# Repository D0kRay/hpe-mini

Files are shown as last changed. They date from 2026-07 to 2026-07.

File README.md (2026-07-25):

# hpe-mini

Clean Hellen One starter structure for a custom rusEFI-compatible PCB.

## Repository Layout
- `hellen-one/` - Hellen One scripts and modules (git submodule)
- `kicad-libraries/` - shared KiCad libraries (git submodule)
- `boards/` - generated board outputs by revision
- `docs/` - project notes and pinout plans
- `gerber/` - frame export staging from KiCad

## Quick Start
1. Create your KiCad frame project at repository root.
2. Use revision settings from `revision.txt`.
3. Run `./step1_build_docker.sh` once to build local Hellen image.
4. Run `./step2_copy.sh` to export frame data.
5. Run `./step3_create_board.sh` to merge modules and generate fab outputs.

## GitHub Automation
This repository includes reusable workflows in `.github/workflows/` that call
the upstream Hellen One board creation pipelines.

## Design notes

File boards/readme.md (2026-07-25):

Generated board outputs are organized by revision.

Expected first output path:
- boards/hpe_mini-a/

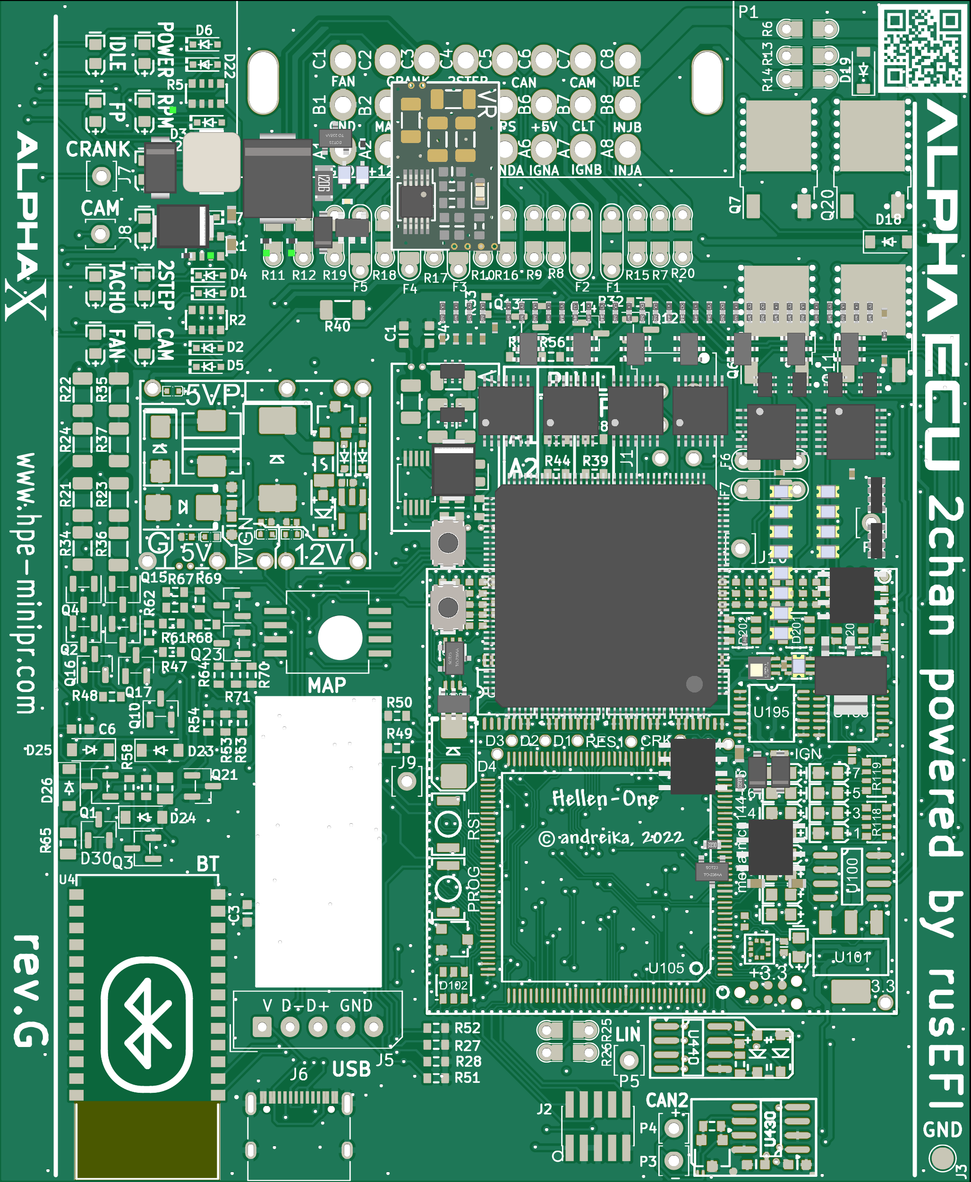
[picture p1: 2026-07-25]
boards/hpe_mini-a/board/hpe_mini-a.png

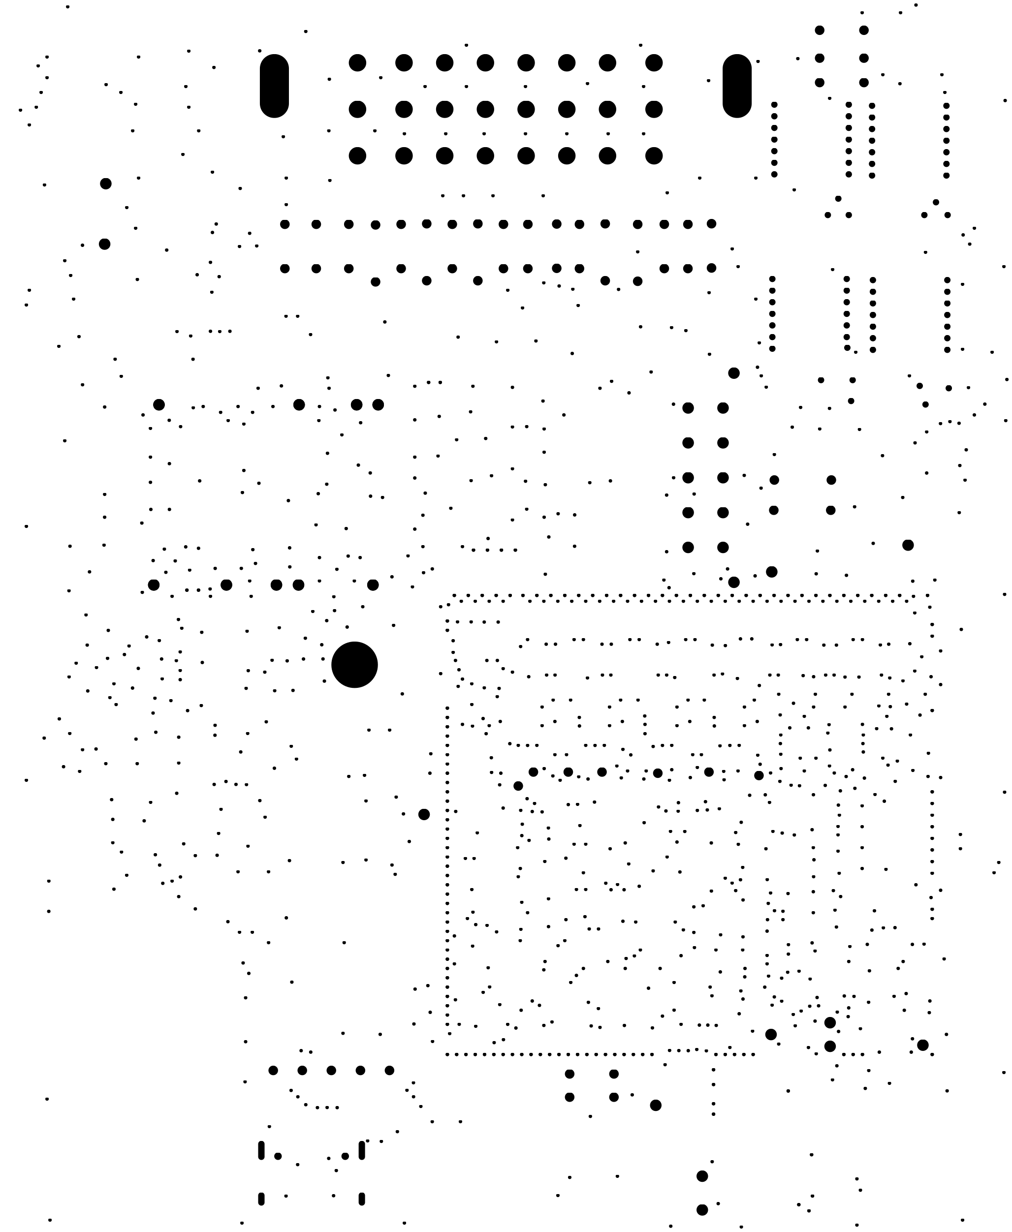
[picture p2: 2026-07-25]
boards/hpe_mini-a/board/misc/hpe_mini-a-outline.png

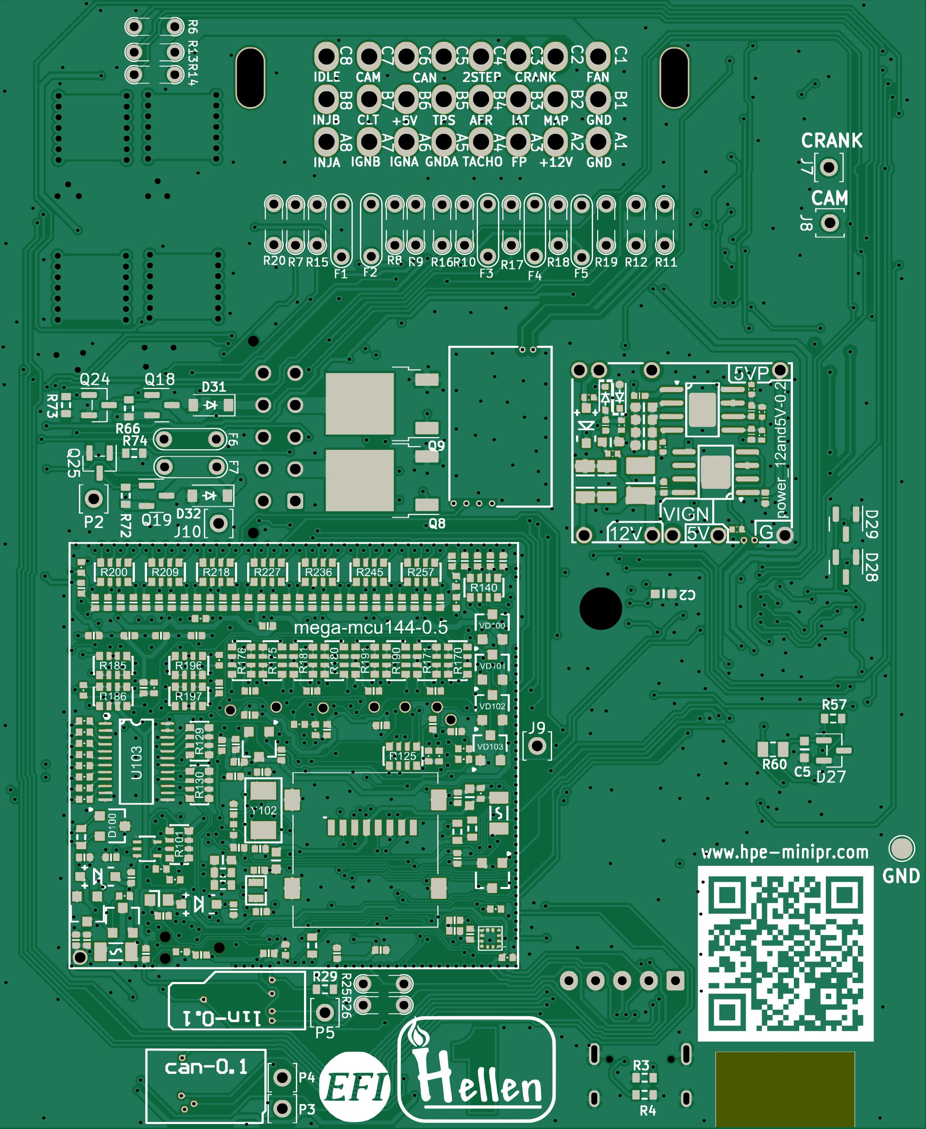
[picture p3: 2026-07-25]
boards/hpe_mini-a/board/misc/hpe_mini-a-bottom.png

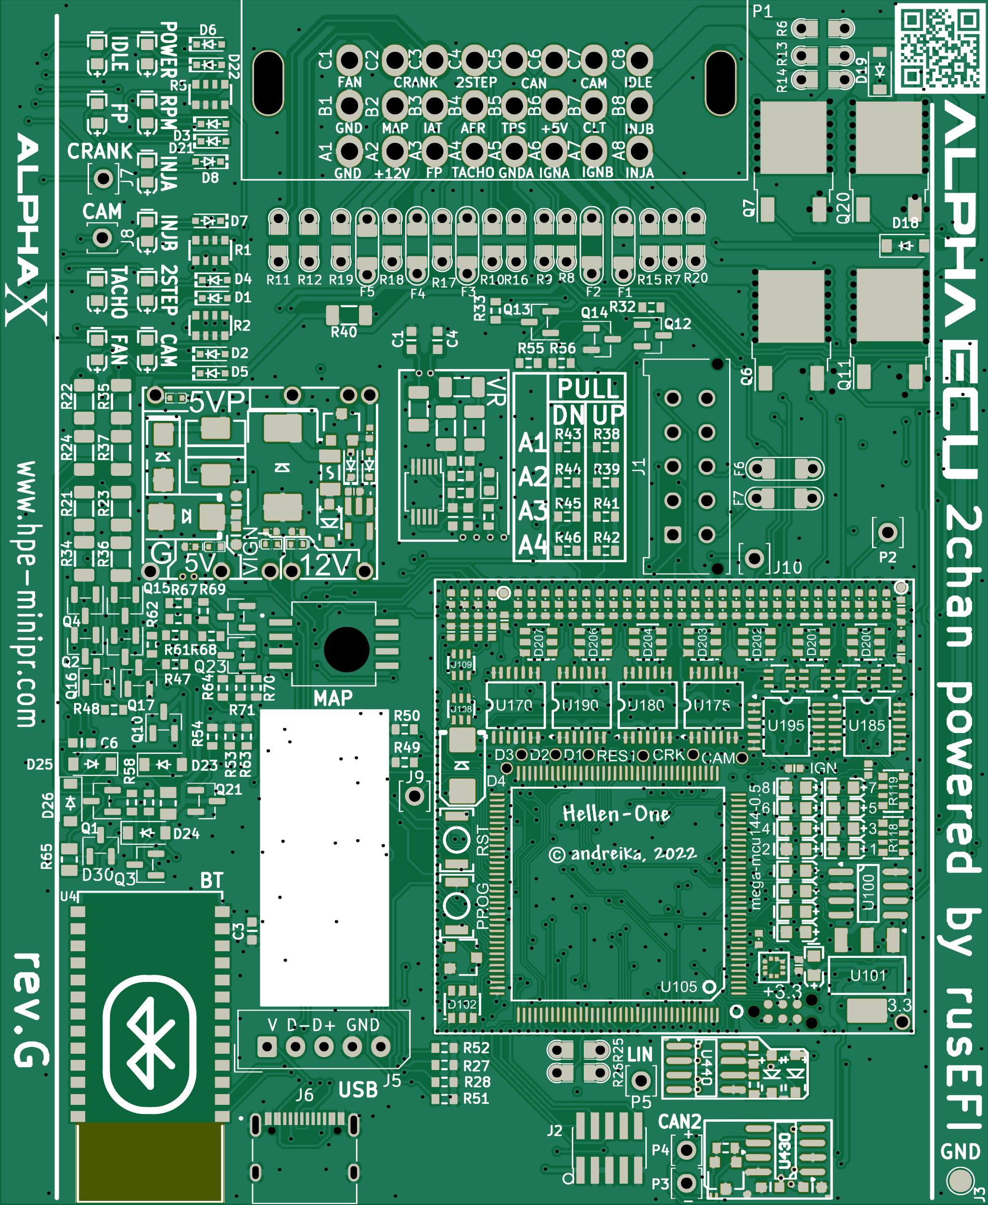
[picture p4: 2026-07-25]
boards/hpe_mini-a/board/misc/hpe_mini-a-top.png

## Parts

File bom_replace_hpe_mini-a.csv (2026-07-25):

# remove the jumper connection from VCC_PP1 to +5V: we need +12v power supply for push-pull outputs.
R309
# remove +5V pull-ups from SPI1 | because we use it with +3.3v accelerometer
R103
R105
# remove jumper resistor connecting BOOT1 with A22 input line | because we use STM32F4
R131
# remove built-in V5A power source from the MCU module | and use an external source (TLS115)
L101
# STM32
U105 | STM32F407ZGT7 | LQFP144 | C1337111
# Alpha2Ch: We don't use SENS1-SENS4 and AUX1-AUX4 | so we don't need these OpAmps
U102
U109
# DC-DC Inductor
L421 | MWSA0503S-100MT | MWSA0503 | C408412
L420 | LBC3225T2R2MR | L1210 | C223413
# LMR14020->LMR14030 (more power | no problem)
U420 | LMR14030 | SOP8 | C182078
#fuses
F410 | nSMD050-24V | SMD1206 | C70076
F300 | nSMD050-24V | SMD1206 | C70076
F1 | Fuse-5A-1206 | SMD1206 | C553924
F2 | Fuse-5A-1206 | SMD1206 | C553924
F3 | Fuse-5A-1206 | SMD1206 | C553924
#power distribution
U103 | AP2331W-7 | SOT-23 | C460346
U480 | AP2331W-7 | SOT-23 | C460346
# JLC-BOM stock shortages...
U420 | LMR14020SDDAR | SOP8 | C187824
S1 | TS-1088R-02026 | SMD-2_2.9x3.9x1.7 | C455280
S2 | TS-1088R-02026 | SMD-2_2.9x3.9x1.7 | C455280
F5 | 0437005.WR | PAD-1206-PAD | C99541
L420 | NLV32T-2R2J-PF | L1210 | C89016
R4 | 4D03WGF1001T5E | R0603-4 | C425239
# no TLS115
U1 | TLS115 | PG-DSO-8-43
# no Cortex 5x2 header
J2 | Cortex_Debug | PinHeader_2x05_P1.27mm_Vertical_SMD
# no MAP sensor
U3 | MPXH6400A | MPXH6400A-SSOP8
# no smart MOSFETs
Q6 | VND14NV04-E | DPAK
Q7 | VND14NV04-E | DPAK
Q8 | VND14NV04-E | DPAK
Q9 | VND14NV04-E | DPAK

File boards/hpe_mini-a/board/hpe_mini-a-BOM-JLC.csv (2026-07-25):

Comment | Designator | Footprint | LCSC Part #
100n | C2, C3, C5, C6, C772, C440, C430, C431 | C0603 | C14663
1N4148WS | D1, D2, D3, D4, D5, D6, D7, D8, D21, D22, D410, D412, D413, D414 | SOD-323 | C2128
LED-RED-0603 | D9, D13, D14, D15, D16, D17, D103 | LED-0603 | C2286
LED-WHITE-0603 | D10, D11, D12 | LED-0603 | C2290
B5819W | D18, D19, D23, D24, D25, D26, D31, D32, D416, D417, D101, D107, D440, D441 | SOD-123 | C8598
LED-GREEN-0603 | D20, D104, D108, D771 | LED-0603 | C72043
PSM712-LF | D27, D30, D411 | SOT-23 | C32677
BAT54S | D28, D29, VD100, VD101, VD102, VD103 | SOT-23 | C47546
nSMD005 | F6, F7 | PAD-1206-PAD | C70064
nSMD050 | F4 | PAD-1206-PAD | C720075
430451012 | J1 | Molex_Micro-Fit_3.0_43045-1012_2x05_P3.00mm_Vertical | C239457
USB_C_Receptacle_USB2.0 | J6 | USB_C_Receptacle_XKB_U262-16XN-4BVC11 | C2927038
HCCPHPE24BKA90F | P1 | 33311-24AW-2 | C5349068
AO3401A | Q1, Q2, Q4, Q5, Q12, Q13, Q15, Q100, Q102 | SOT-23 | C15127
AO3400A | Q3, Q10, Q14, Q16, Q17, Q21, Q22, Q23, Q24, Q25, Q101, Q103 | SOT-23 | C20917
VND14NV04-E | Q11, Q20 | DPAK | C155647
PJM2319PSA | Q18, Q19 | SOT-23 | C411720
4.7k | R1, R2, R5, R125, R170, R171, R175, R176, R180, R181, R185, R186, R190, R191, R196, R197, R200, R209, R218, R227, R236, R245, R257 | R0603-4 | C66697
5.6k | R3 | R0603 | C23189
Jumper-Pad-Pad | R6, R7, R8, R9, R10, R11, R12, R13, R14, R15, R16, R17, R18, R19, R20 | PAD-0805-PAD | C17477
2k | R21, R23, R34, R36 | R1206 | C17944
4.7k | R22, R24, R35, R37, R771, R772, R773, R774 | R1206 | C17936
4.7k | R27, R28, R29, R47, R48, R49, R50, R51, R52, R53, R54, R55, R56, R57, R58, R59, R61, R62, R63, R64, R66, R70, R71, R72, R73, R74 | R0603 | C23162
3.3k | R30, R67 | R0603 | C22978
750 | R31 | R0805 | C17818
2.7k | R32, R33 | R0603 | C13167
SMD1206B035TF/16 | R40, F100, F101 | R1206 | C269114
680k | R43, R44, R45, R46 | R0603 | C25822
220 | R60 | R0805 | C17557
470 | R65 | R0805 | C17710
1.2k | R68, R69 | R0603 | C22765
47u | C410, C412 | C1206 | C96123
100n | C411, C413, C420 | C0402 | C307331
1u | C414, C415 | C0402 | C52923
10u | C421, C422, C423, C424, C425, C426 | C0603 | C96446
4.7u | C427 | C0603 | C19666
10n | C428, C202, C208, C209, C210, C211, C212, C213, C214, C215 | C0402 | C15195
220p | C429 | C0402 | C1530
SMCJ30A | D418 | SMC | C310046
SS34 | D420 | SMA | C8678
P6SMB6.8CA | D421, D205 | SMB | C78395
MHT136UGCT | LED1, LED2, LED3, LED4 | LED0402 | C434447
6.8k | R410, R413 | R0402 | C25917
33k | R411, R424, R425 | R0402 | C25779
1 | R420 | R0402 | C25086
10k | R421, R426, R427, R102, R107, R108, R109, R121, R124, R126, R127, R128, R132, R135, R136, R137, R138, R139, R141, R142, R228, R229, R230, R231, R232, R233, R234, R235, R246, R247, R248, R249, R250, R251, R252, R253 | R0402 | C25744
68k | R422 | R0402 | C36871
12k | R423 | R0402 | C25752
4.7k | R428, R144, R210, R211, R212, R213, R214, R215, R216, R217, R219, R220, R223, R224 | R0402 | C25900
MIC5205-3.3YM5 | U410 | SOT23-5 | C37970
TLS115 | U411 | PG-DSO-8 EP | C540242
TJA1051T/3/1J | U100, U430 | SO8 | C38695
SRV05-4-P-T7 | D102, D200, D201, D202, D203, D204, D206, D207 | SOT23-6 | C85364
SN74LVC1G06DCKR | U110 | SOT-353 | C7828
PESD1CAN | D100, D430 | SOT-23 | C343993
NC7SB3157P6X | U270, U275, U280, U285 | SOT-363 | C87403
Molex MicroSD 47219-2001 | J100 | SDAMB-012 | C164170
MCP6004 | U170, U175, U180, U185, U190, U195 | TSSOP14 | C50282
LPS22HBTR | U107 | HLGA-10L | C94049
LIS2DH12TR | U106 | LGA12 | C110926
LED-YELLOW-0603 | D106 | LED-0603 | C72038
LED-BLUE-0603 | D105, D109, D110, D111, D112, D113, D114, D115, D116 | LED-0603 | C72041
LDL1117S33R | U101 | SOT-223 | C435835
BTN | S100, S101 | SMD-2_2.9x3.9x1.7 | C115357
BLM18AG601SN1D | L100 | L0603 | C19330
680k | R201, R202, R203, R204, R205, R206, R207, R208, R221, R222, R225, R226, R237, R238, R239, R240, R241, R242, R243, R244, R259, R260, R261, R262, R263, R264, R265, R266 | R0402 | C163456
510 | R133, R134 | R0603 | C23193
510 | R254, R255, R256, R258 | R0402 | C25123
470 | R101, R118, R119 | R0603-4 | C25510
120 | R100, R430 | R0603 | C22787
100n | C100, C101, C105, C108, C109, C110, C111, C112, C113, C118, C119, C120, C121, C122, C124, C126, C127, C128, C129, C130, C134, C147, C170, C175, C180, C185, C190, C195, C204, C205, C206, C207, C216, C217, C218, C219, C220, C221, C222, C230, C231, C232, C233, C270, C275, C280, C285 | C0402 | C1525
100 | R104, R106 | R0603 | C22775
74LVC2G17GW,125 | U108 | SOT-363 | C80500
33k | R120 | R0603 | C4216
32.768 kHz | Y101 | SMD2012 | C99009
22u | C117, C123, C773 | C0603 | C59461
20 MHz | Y102 | SMD5032 | C112566
18p | C132, C136 | C0402 | C1549
12p | C115, C116 | C0402 | C1547
10k | R129, R130, R140 | R0603-4 | C29718
10 | R110, R111, R112, R113, R114, R115, R116, R117 | R0402 | C25077
5.1k | R195 | R0402 | C25905
4.7u | C102, C103, C104, C106, C107, C137, C138, C140 | C0402 | C23733
2.2u | C114, C131, C223, C224, C229 | C0402 | C12530
2.2k | R122, R123, R146, R147 | R0402 | C25879
1u | C133 | C0603 | C519560
1n | C135, C139, C141, C142, C143, C144, C145, C146, C200, C201, C203, C225, C226, C227, C228 | C0402 | C1523
0 | R143, R145 | R0402 | C17168
1n | C771 | C0603 | C1588
10k | R776, R777 | R0603 | C25804
MAX9924UAUB+ | U771 | MSOP-10_3x3mm_P0.5mm | C143633
1k | R440 | R0603 | C21190
TJA1021T/20/CM | U440 | SO8 | C128810
STM32F407ZGT7 | U105 | LQFP144 | C1337111
MWSA0503S-100MT | L421 | MWSA0503 | C408412
nSMD050-24V | F410, F300 | SMD1206 | C70076
Fuse-5A-1206 | F1, F2, F3 | SMD1206 | C553924
AP2331W-7 | U103, U480 | SOT-23 | C460346
LMR14020SDDAR | U420 | SOP8 | C187824
TS-1088R-02026 | S1, S2 | SMD-2_2.9x3.9x1.7 | C455280
0437005.WR | F5 | PAD-1206-PAD | C99541
NLV32T-2R2J-PF | L420 | L1210 | C89016
4D03WGF1001T5E | R4 | R0603-4 | C425239

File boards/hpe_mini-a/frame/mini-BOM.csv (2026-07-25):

Comment | Designator | Footprint | LCSC Part #
~ | C1 | C0603
100n | C2 | C0603 | C14663
100n | C3 | C0603 | C14663
~ | C4 | C0603
100n | C5 | C0603 | C14663
100n | C6 | C0603 | C14663
1N4148WS | D1 | SOD-323 | C2128
1N4148WS | D2 | SOD-323 | C2128
1N4148WS | D3 | SOD-323 | C2128
1N4148WS | D4 | SOD-323 | C2128
1N4148WS | D5 | SOD-323 | C2128
1N4148WS | D6 | SOD-323 | C2128
1N4148WS | D7 | SOD-323 | C2128
1N4148WS | D8 | SOD-323 | C2128
LED-RED-0603 | D9 | LED-0603 | C2286
LED-WHITE-0603 | D10 | LED-0603 | C2290
LED-WHITE-0603 | D11 | LED-0603 | C2290
LED-WHITE-0603 | D12 | LED-0603 | C2290
LED-RED-0603 | D13 | LED-0603 | C2286
LED-RED-0603 | D14 | LED-0603 | C2286
LED-RED-0603 | D15 | LED-0603 | C2286
LED-RED-0603 | D16 | LED-0603 | C2286
LED-RED-0603 | D17 | LED-0603 | C2286
B5819W | D18 | SOD-123 | C8598
B5819W | D19 | SOD-123 | C8598
LED-GREEN-0603 | D20 | LED-0603 | C72043
1N4148WS | D21 | SOD-323 | C2128
1N4148WS | D22 | SOD-323 | C2128
B5819W | D23 | SOD-123 | C8598
B5819W | D24 | SOD-123 | C8598
B5819W | D25 | SOD-123 | C8598
B5819W | D26 | SOD-123 | C8598
PSM712-LF | D27 | SOT-23 | C32677
BAT54S | D28 | SOT-23 | C47546
BAT54S | D29 | SOT-23 | C47546
PSM712-LF | D30 | SOT-23 | C32677
B5819W | D31 | SOD-123 | C8598
B5819W | D32 | SOD-123 | C8598
nSMD005 | F1 | PAD-1206-PAD | C70064
nSMD005 | F2 | PAD-1206-PAD | C70064
nSMD050 | F3 | PAD-1206-PAD | C720075
nSMD050 | F4 | PAD-1206-PAD | C720075
12H1500D | F5 | PAD-1206-PAD | C182446
nSMD005 | F6 | PAD-1206-PAD | C70064
nSMD005 | F7 | PAD-1206-PAD | C70064
DISCLAIMER | G1
LOGO | G2 | LOGO
LOGO | G3 | LOGO
LOGO_AlphaECU | G4 | hpe-mini_logo_AlphaECU
LOGO_hpe-mini | G5 | hpe-mini_logo_hpe-mini
HPE-MINI_QR_CODE | G6 | hpe-mini_qr_code
430451012 | J1 | Molex_Micro-Fit_3.0_43045-1012_2x05_P3.00mm_Vertical | C239457
Cortex_Debug | J2 | PinHeader_2x05_P1.27mm_Vertical_SMD | C448647
Conn_01x01 | J3 | TestPoint_Pad_D2.0mm
Conn_01x01 | J4 | TestPoint_Pad_D2.0mm
Conn_01x05_Male | J5 | Molex_SPOX_5267-05A_1x05_P2.50mm_Vertical
USB_C_Receptacle_USB2.0 | J6 | USB_C_Receptacle_XKB_U262-16XN-4BVC11 | C2927038
Pad | J7 | PAD-TH
Pad | J8 | PAD-TH
Pad | J9 | PAD-TH
Pad | J10 | PAD-TH
Module:power_12and5V/0.2 | M1 | power_12and5V
Module:mega-mcu144/0.5 | M2 | mega-mcu144
Module:vr-max9924/0.1 | M3 | vr-max9924
Module:lin/0.1 | M4 | lin
Module:can/0.1 | M8 | can
HCCPHPE24BKA90F | P1 | 33311-24AW-2 | C5349068
Pad | P2 | PAD-TH
Pad | P3 | PAD-TH
Pad | P4 | PAD-TH
Pad | P5 | PAD-TH
AO3401A | Q1 | SOT-23 | C15127
AO3401A | Q2 | SOT-23 | C15127
AO3400A | Q3 | SOT-23 | C20917
AO3401A | Q4 | SOT-23 | C15127
AO3401A | Q5 | SOT-23 | C15127
VND14NV04-E | Q6 | DPAK | C155647
VND14NV04-E | Q7 | DPAK | C155647
VND14NV04-E | Q8 | DPAK | C155647
VND14NV04-E | Q9 | DPAK | C155647
AO3400A | Q10 | SOT-23 | C20917
VND14NV04-E | Q11 | DPAK | C155647
AO3401A | Q12 | SOT-23 | C15127
AO3401A | Q13 | SOT-23 | C15127
AO3400A | Q14 | SOT-23 | C20917
AO3401A | Q15 | SOT-23 | C15127
AO3400A | Q16 | SOT-23 | C20917
AO3400A | Q17 | SOT-23 | C20917
PJM2319PSA | Q18 | SOT-23 | C411720
PJM2319PSA | Q19 | SOT-23 | C411720
VND14NV04-E | Q20 | DPAK | C155647
AO3400A | Q21 | SOT-23 | C20917
AO3400A | Q22 | SOT-23 | C20917
AO3400A | Q23 | SOT-23 | C20917
AO3400A | Q24 | SOT-23 | C20917
AO3400A | Q25 | SOT-23 | C20917
4.7k | R1 | R0603-4 | C66697
4.7k | R2 | R0603-4 | C66697
5.6k | R3 | R0603 | C23189
5.6k | R4 | R0603 | C23189
4.7k | R5 | R0603-4 | C66697
Jumper-Pad-Pad | R6 | PAD-0805-PAD | C17477
Jumper-Pad-Pad | R7 | PAD-0805-PAD | C17477
Jumper-Pad-Pad | R8 | PAD-0805-PAD | C17477
Jumper-Pad-Pad | R9 | PAD-0805-PAD | C17477
Jumper-Pad-Pad | R10 | PAD-0805-PAD | C17477
Jumper-Pad-Pad | R11 | PAD-0805-PAD | C17477
Jumper-Pad-Pad | R12 | PAD-0805-PAD | C17477
Jumper-Pad-Pad | R13 | PAD-0805-PAD | C17477
Jumper-Pad-Pad | R14 | PAD-0805-PAD | C17477
Jumper-Pad-Pad | R15 | PAD-0805-PAD | C17477
Jumper-Pad-Pad | R16 | PAD-0805-PAD | C17477
Jumper-Pad-Pad | R17 | PAD-0805-PAD | C17477
Jumper-Pad-Pad | R18 | PAD-0805-PAD | C17477
Jumper-Pad-Pad | R19 | PAD-0805-PAD | C17477
Jumper-Pad-Pad | R20 | PAD-0805-PAD | C17477
2k | R21 | R1206 | C17944
4.7k | R22 | R1206 | C17936
2k | R23 | R1206 | C17944
4.7k | R24 | R1206 | C17936
Jumper-Pad-Pad | R25 | PAD-0805-PAD
Jumper-Pad-Pad | R26 | PAD-0805-PAD
4.7k | R27 | R0603 | C23162
4.7k | R28 | R0603 | C23162
4.7k | R29 | R0603 | C23162
3.3k | R30 | R0603 | C22978
750 | R31 | R0805 | C17818
2.7k | R32 | R0603 | C13167
2.7k | R33 | R0603 | C13167
2k | R34 | R1206 | C17944
4.7k | R35 | R1206 | C17936
2k | R36 | R1206 | C17944
4.7k | R37 | R1206 | C17936
DNP | R38 | R0603
DNP | R39 | R0603
SMD1206B035TF/16 | R40 | R1206 | C269114
DNP | R41 | R0603
DNP | R42 | R0603
680k | R43 | R0603 | C25822
680k | R44 | R0603 | C25822
680k | R45 | R0603 | C25822
680k | R46 | R0603 | C25822
4.7k | R47 | R0603 | C23162
4.7k | R48 | R0603 | C23162
4.7k | R49 | R0603 | C23162
4.7k | R50 | R0603 | C23162
4.7k | R51 | R0603 | C23162
4.7k | R52 | R0603 | C23162
4.7k | R53 | R0603 | C23162
4.7k | R54 | R0603 | C23162
4.7k | R55 | R0603 | C23162
4.7k | R56 | R0603 | C23162
4.7k | R57 | R0603 | C23162
4.7k | R58 | R0603 | C23162
4.7k | R59 | R0603 | C23162
220 | R60 | R0805 | C17557
4.7k | R61 | R0603 | C23162
4.7k | R62 | R0603 | C23162
4.7k | R63 | R0603 | C23162
4.7k | R64 | R0603 | C23162
470 | R65 | R0805 | C17710
4.7k | R66 | R0603 | C23162
3.3k | R67 | R0603 | C22978
1.2k | R68 | R0603 | C22765
1.2k | R69 | R0603 | C22765
4.7k | R70 | R0603 | C23162
4.7k | R71 | R0603 | C23162
4.7k | R72 | R0603 | C23162
4.7k | R73 | R0603 | C23162
4.7k | R74 | R0603 | C23162
MPXHZ6400AC6T1 | U1 | MPXH6400A-SSOP8 | C511770
JDY-33 | U4 | JDY-33

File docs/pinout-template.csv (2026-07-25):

Connector | Pin | Signal | Direction | Voltage | Notes
J1 | 1 | VBAT | IN | 12V
J1 | 2 | GND | PWR | 0V
J1 | 3 | IN_CRANK | IN | 0-5V or VR
J1 | 4 | IN_CAM | IN | 0-5V
J1 | 5 | OUT_INJ1 | OUT | 12V low-side
J1 | 6 | OUT_IGN1 | OUT | Logic/driver

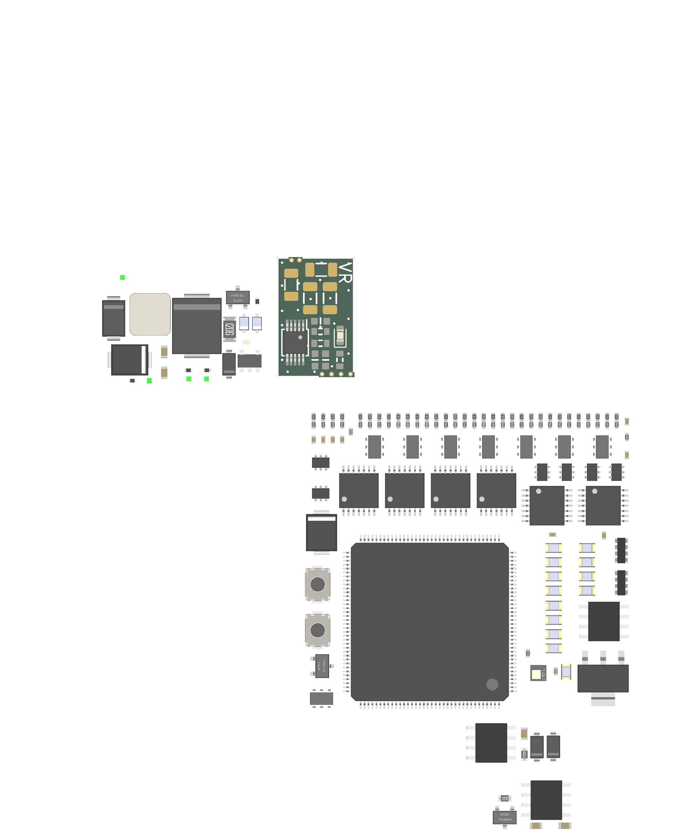
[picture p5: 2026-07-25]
boards/hpe_mini-a/board/misc/hpe_mini-a-components.png

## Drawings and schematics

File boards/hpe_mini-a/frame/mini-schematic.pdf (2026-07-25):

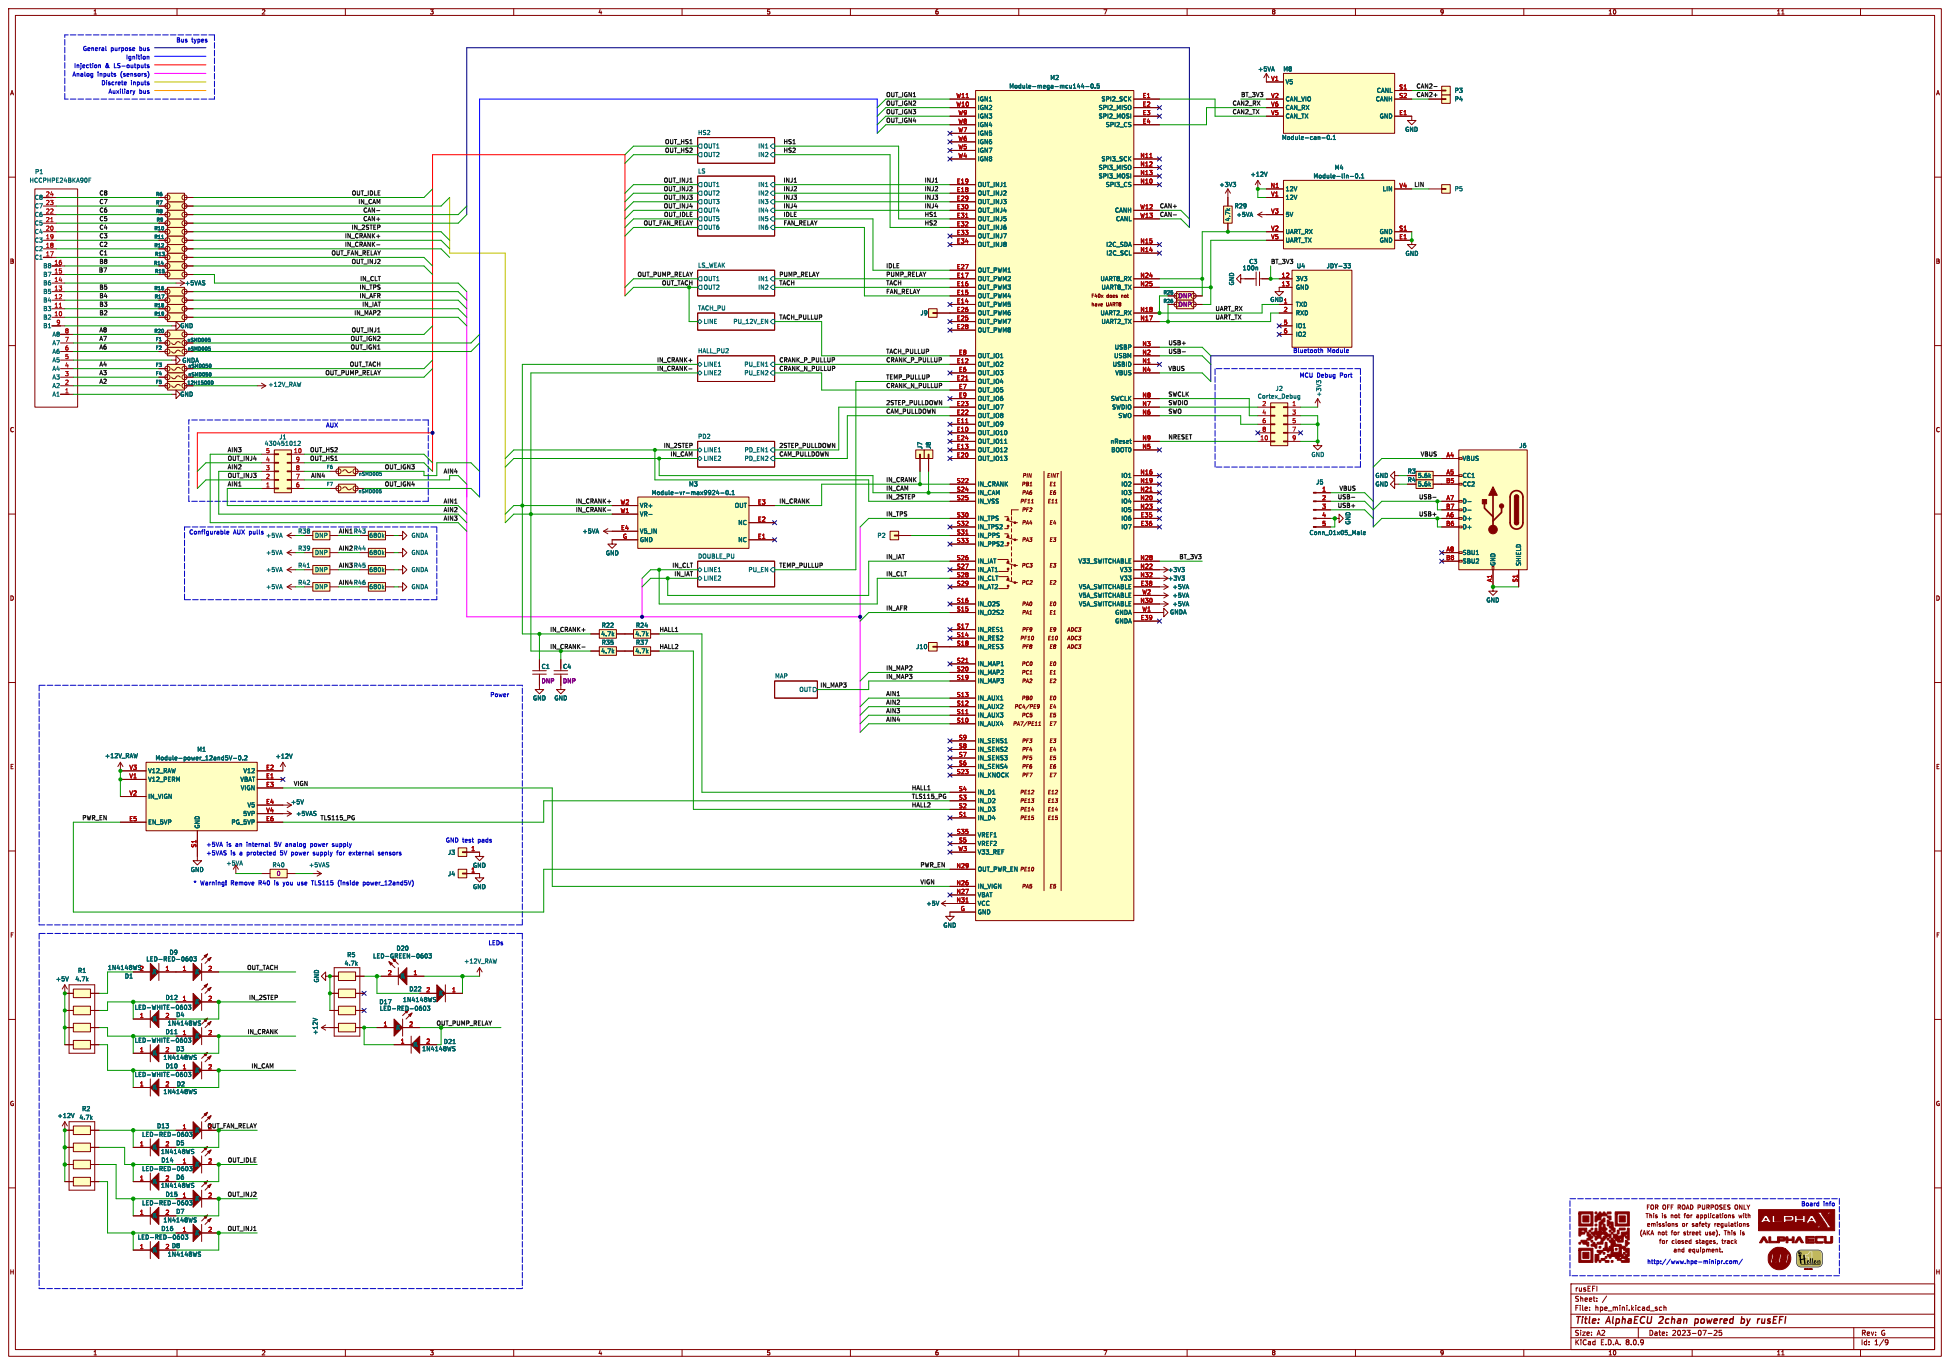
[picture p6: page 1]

4.7k GND GND
GND test padsLEDs Power

for closed stages, track FOR OFF ROAD PURPOSES ONLY

http://www.hpe-minipr.com/

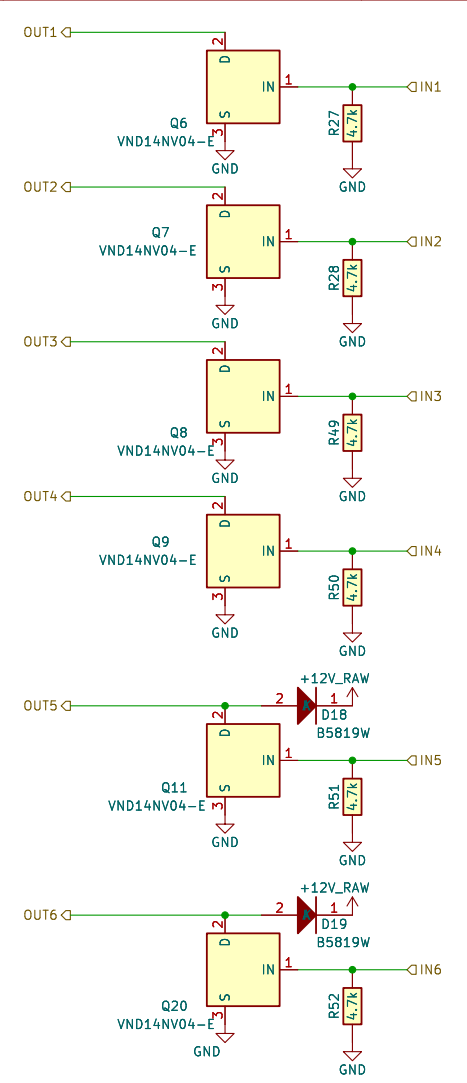
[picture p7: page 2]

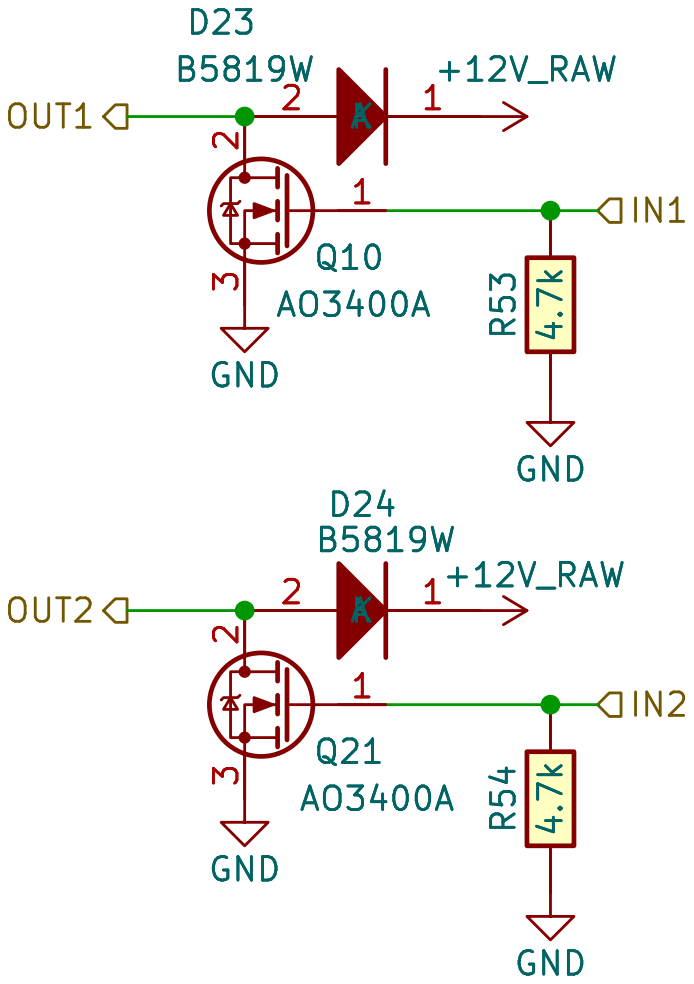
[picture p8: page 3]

Id: 3/9 Title: File: LS_weak.kicad_sch Sheet: /LS_WEAK/

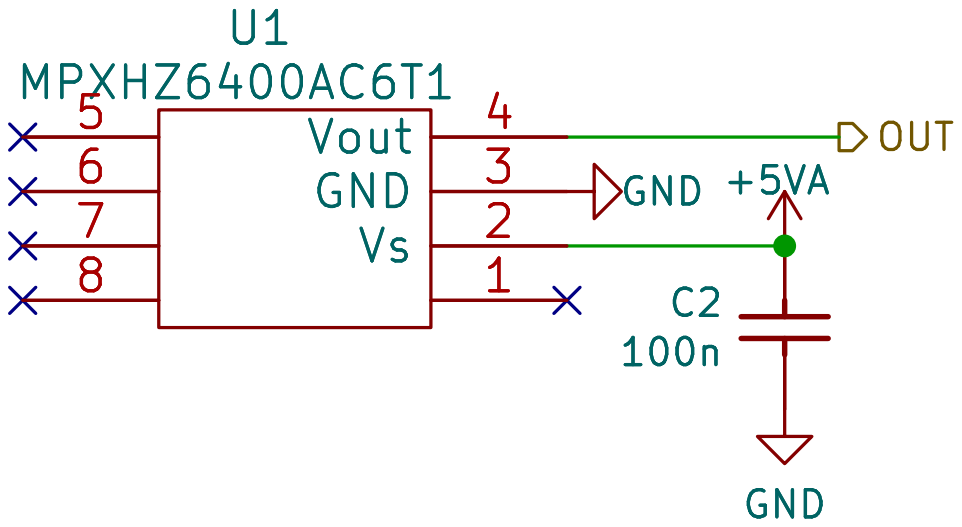
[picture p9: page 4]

Id: 4/9 Title: File: MAP.kicad_sch Sheet: /MAP/

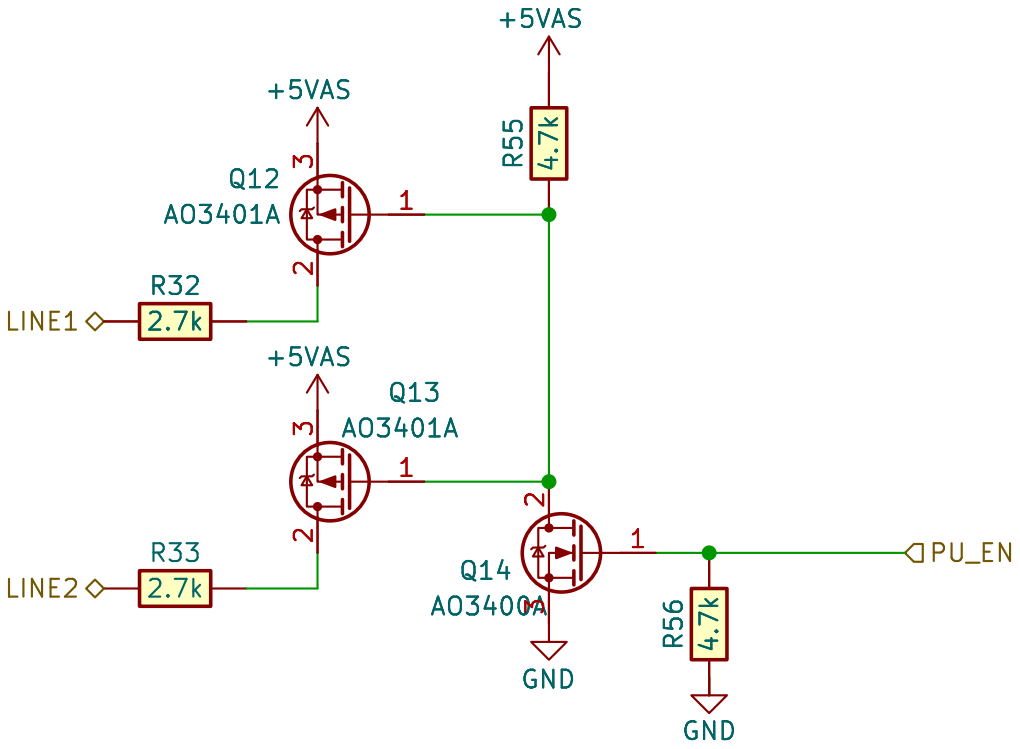
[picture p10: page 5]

Id: 5/9 Title: File: DOUBLE_PU.kicad_sch Sheet: /DOUBLE_PU/

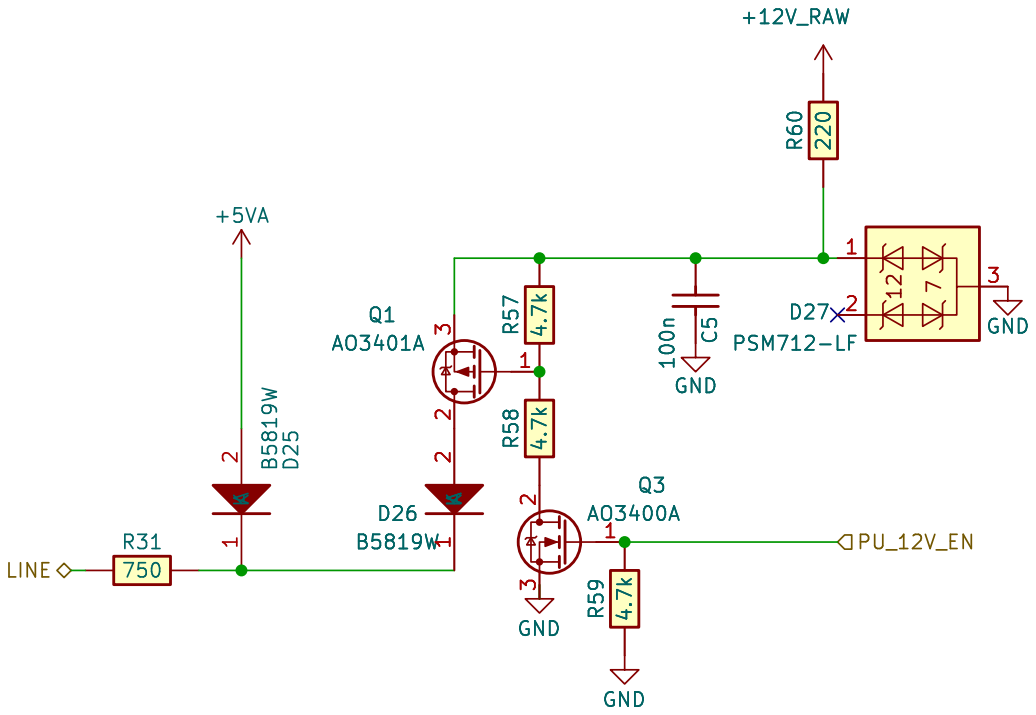
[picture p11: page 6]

Id: 6/9 Title: File: TACH_PU.kicad_sch Sheet: /TACH_PU/

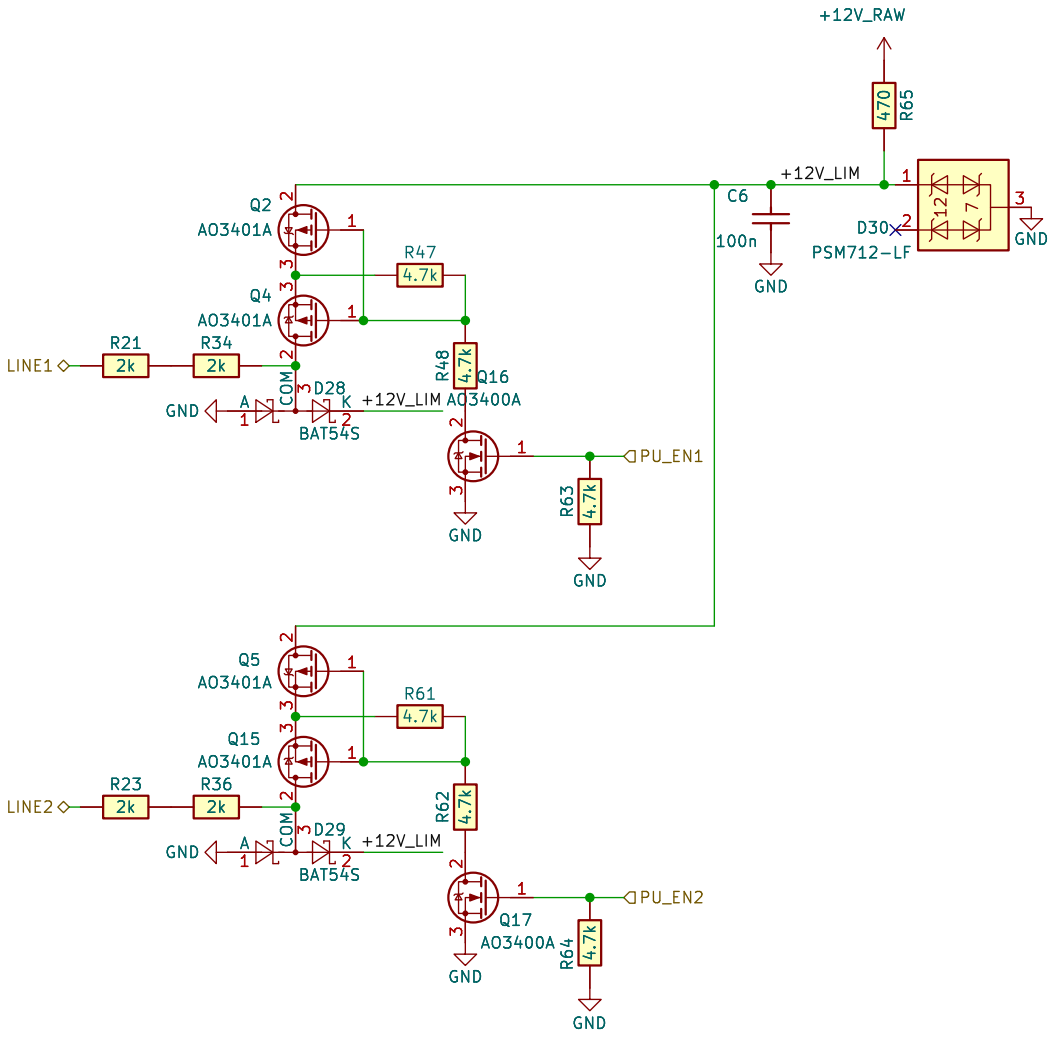
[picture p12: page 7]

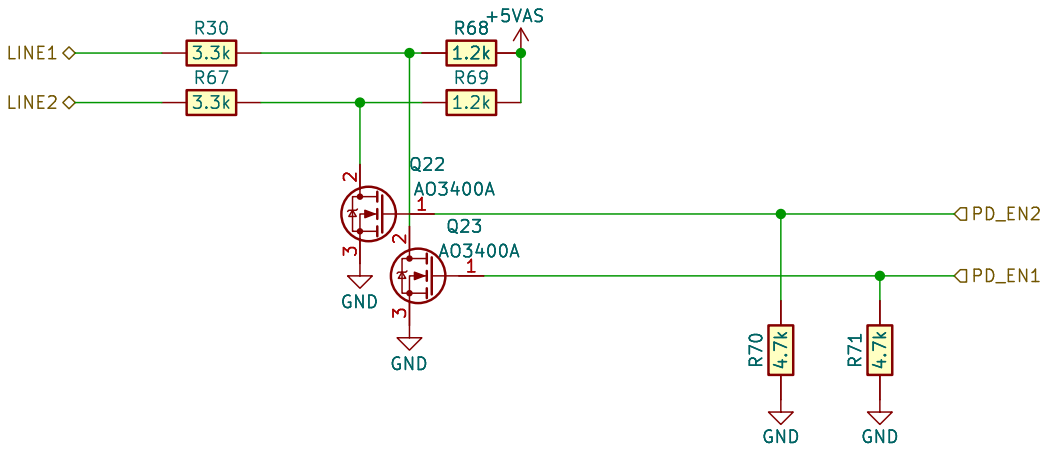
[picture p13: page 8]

Id: 8/9 Title: File: PD2.kicad_sch Sheet: /PD2/ GND

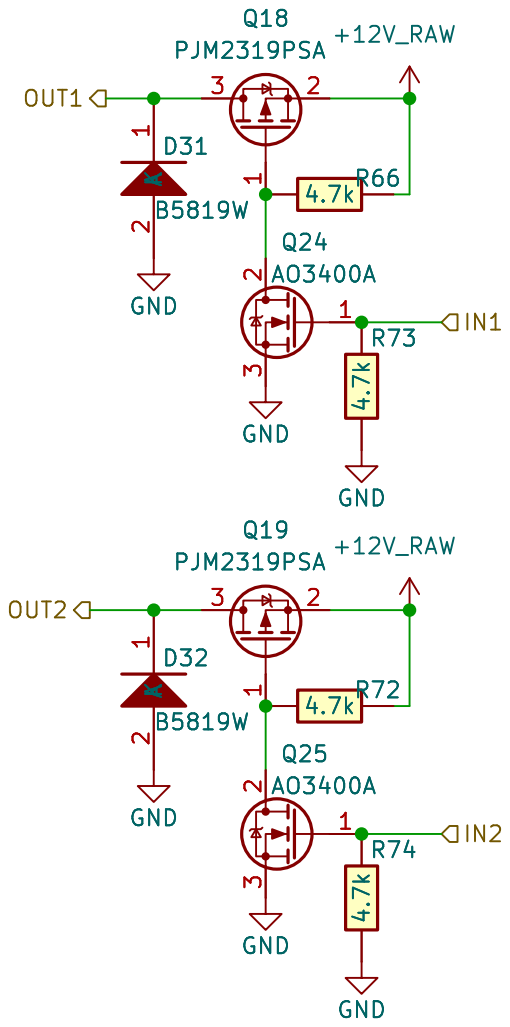
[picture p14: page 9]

Id: 9/9 Title: File: HS2.kicad_sch Sheet: /HS2/

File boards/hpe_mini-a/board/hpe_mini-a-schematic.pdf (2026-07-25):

# LSOUT2 OUT1

LINE1 | PU_EN1 HALL_PU2 OUT1 | IN1 OUT2 | IN2 HS2


4.7k GND GND
GND test padsLEDs Power

for closed stages, track FOR OFF ROAD PURPOSES ONLY

http://www.hpe-minipr.com/

IN 1 D ² S 3Q6 VND14NV04-E | GND
+12V_RAWR²⁸ 4.7k GND R⁵¹ 4.7k K | 1 A 2 | D18 B5819W


D Date: KiCad; E.D.A. 8.0.9 Size: A4; Rev:; +12V_RAW; GND; 2 3Q21 AO3400A GND R53 4.7k GND; +12V_RAW GND R⁵⁴ 4.7k OUT2; IN2 OUT1; 2 GND Q21 AO3400A; 2 3 GND Q10 AO3400A; R⁵⁴ 4.7k GND; +12V_RAW R⁵³ 4.7k GND

Id: 3/9 Title: File: LS_weak.kicad_sch Sheet: /LS_WEAK/

D Date: KiCad; E.D.A. 8.0.9 Size: A4; Rev:; 2 GND; 3 Vout 5; U1 MPXHZ6400AC6T1; GND GND; OUT U1 MPXHZ6400AC6T1

Id: 4/9 Title: File: MAP.kicad_sch Sheet: /MAP/

Id: 5/9 Title: File: DOUBLE_PU.kicad_sch Sheet: /DOUBLE_PU/


Id: 6/9 Title: File: TACH_PU.kicad_sch Sheet: /TACH_PU/

D28 BAT54S A1 | K2 COM3 Q2 AO3401A | 1 ² 3 Q4 AO3401A | 1 2 3 R23



Id: 8/9 Title: File: PD2.kicad_sch Sheet: /PD2/ GND


Id: 9/9 Title: File: HS2.kicad_sch Sheet: /HS2/

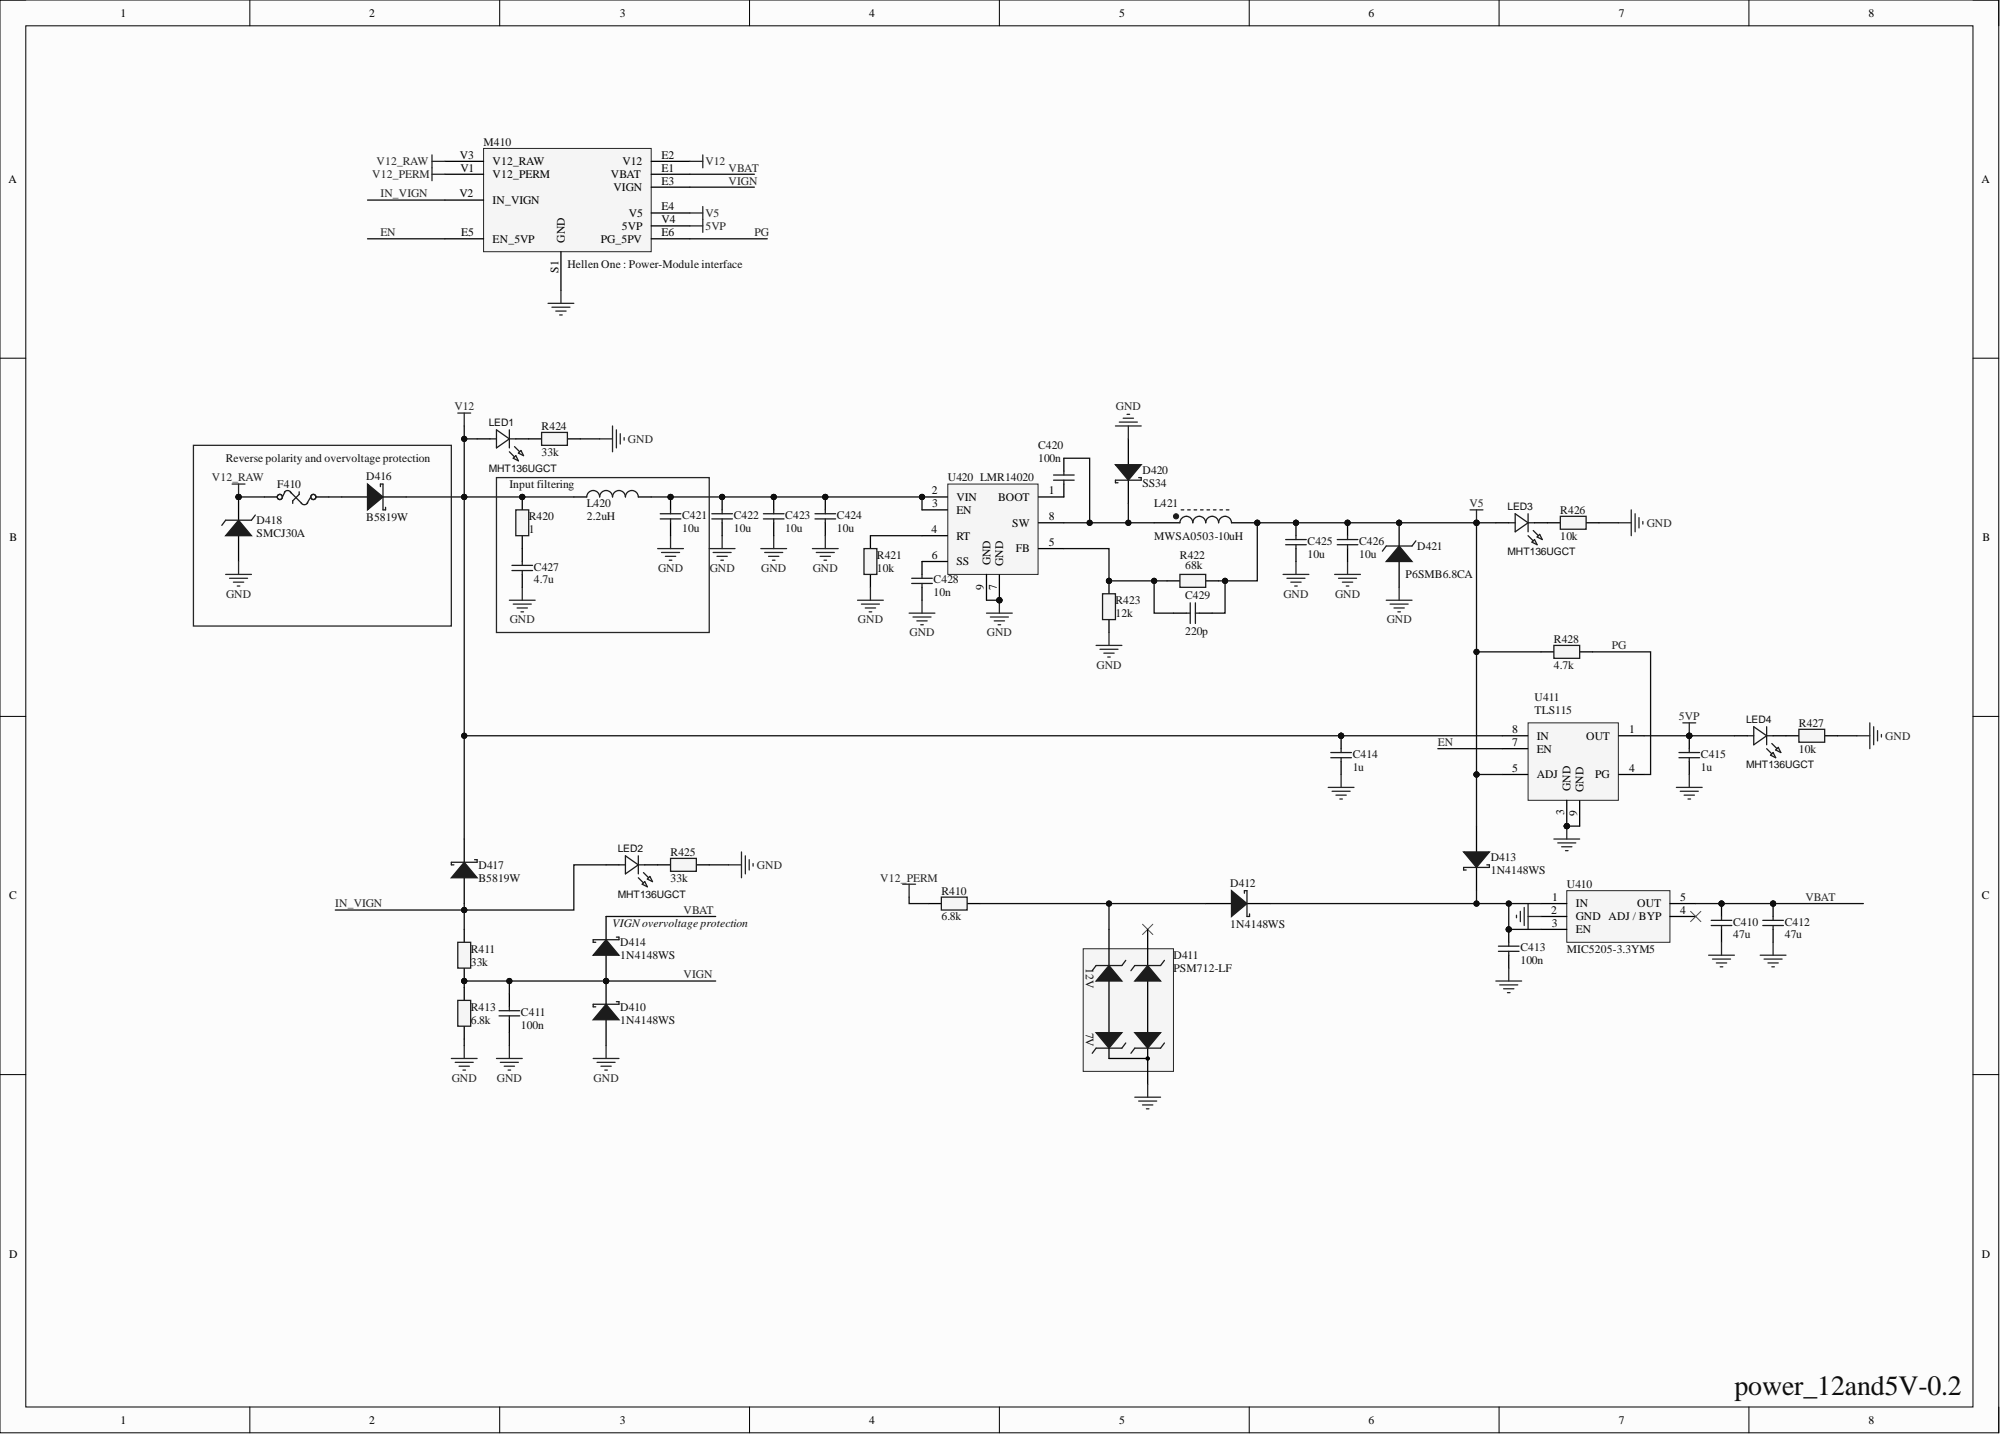
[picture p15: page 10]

Hellen One : Power-Module interface

Reverse polarity and overvoltage protection
F410 V12_RAW

D | D
C | C
B | B
A | A

C270
100n

V5A

IO0
IO1

COM

MUX

B1 1

GND | 2
B0 3 | A | 4

VCC 5

S 6

U270

NC7SB3157P6X

GNDA | GNDA

PIC27001

# PIC27002 COC125

PIU27001

PIU27002

PIU27003 | PIU27004

PIU27005

PIU27006

## COU104

PIC27001

PIU27002

POIO1 PIU27001

POIO0 PIU27003 | PIU27004 POCOM

PIU27006 POMUX

# PIC27002 PIU27005

POIO00Mux1 | POCOM0Mux1
POIO10Mux1 | POMUX0Mux1

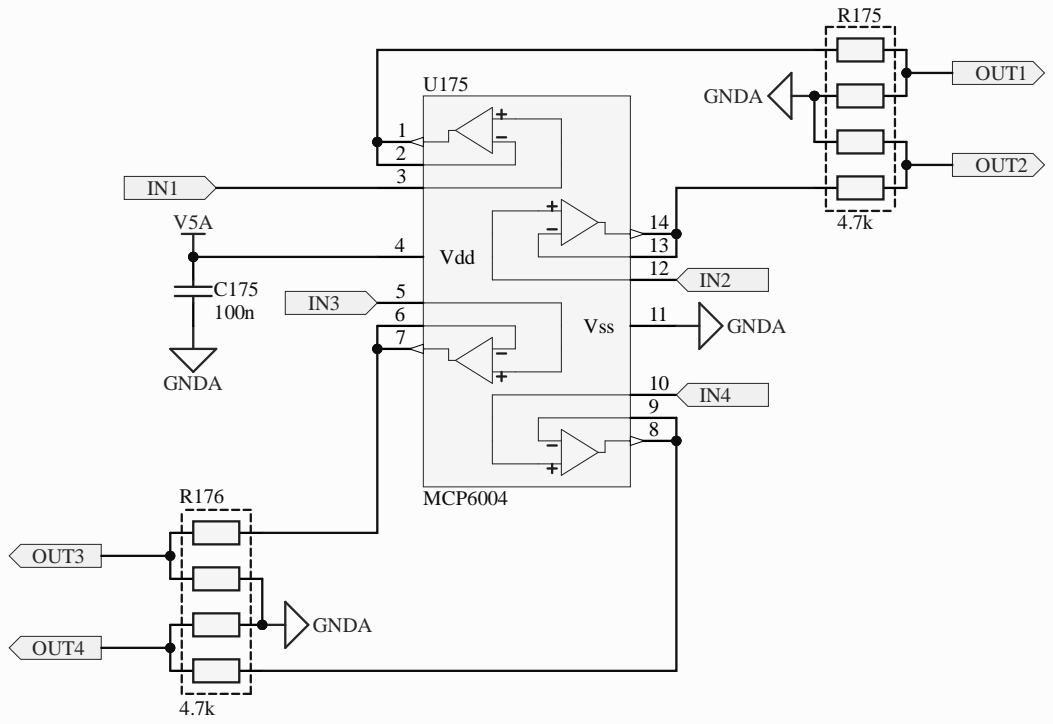
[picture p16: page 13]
Vdd 4; Vss 6; MCP6004; GNDA; OUT1; OUT2; OUT3; OUT4; C175 PIC17501 100n; PIC17502 COC3; PIR17501; PIR17502; PIR17503; PIR17504; PIR17505; PIR17506; PIR17507; PIR17508; COR5; PIR17601; PIR17602; PIR17603; PIR17605; PIR17604; PIR17606; PIR17607; PIR17608; COR6; PIU17501; PIU17502; PIU17503; PIU17504; PIU17505; PIU17506; PIU17507; PIU17508; PIU17509; PIU175010; PIU175011; PIU175012; PIU175013; PIU175014; COU2; PIC17501; POOUT2; POOUT1; POOUT3; POOUT4; POIN1; POIN3 PIU17505; PIU175010 POIN4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

D | D
C | C
B | B
A | A

C275
100n

V5A

IO0
IO1

COM

MUX

B1 1

GND | 2
B0 3 | A | 4

VCC 5

S 6

U275

NC7SB3157P6X

GNDA | GNDA

PIC27501

# PIC27502 COC125

PIU27501

PIU27502

PIU27503 | PIU27504

PIU27505

PIU27506

## COU104

PIC27501

PIU27502

POIO1 PIU27501

POIO0 PIU27503 | PIU27504 POCOM

PIU27506 POMUX

# PIC27502 PIU27505

POIO00Mux2 | POCOM0Mux2
POIO10Mux2 | POMUX0Mux2

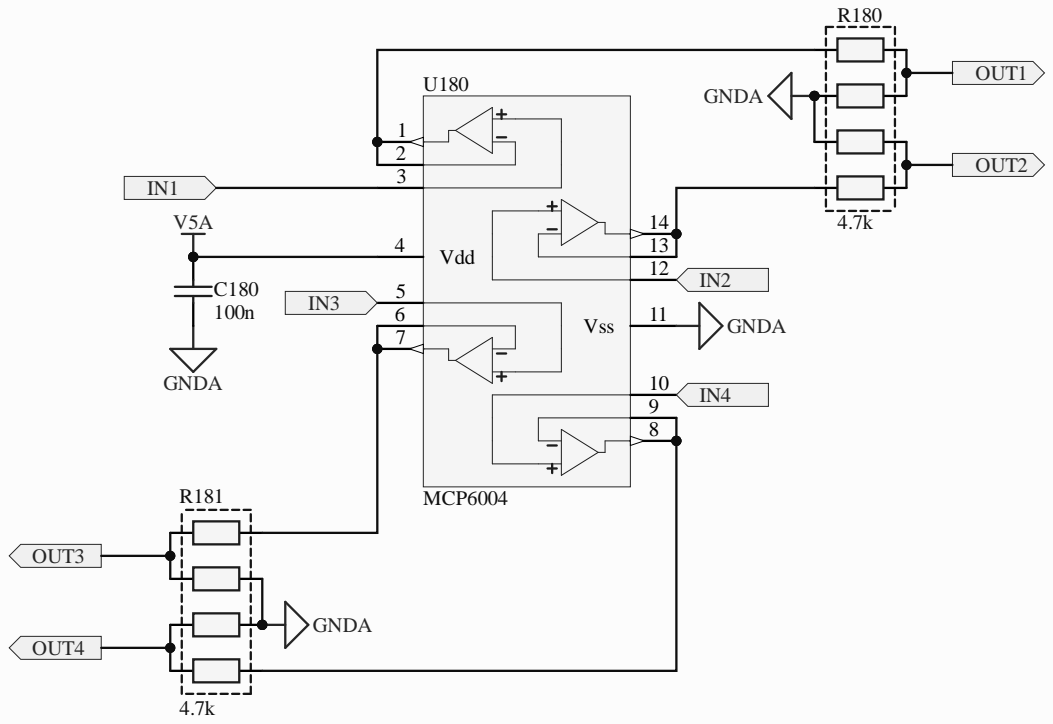
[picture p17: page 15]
Vdd 4; Vss 6; MCP6004; GNDA; OUT1; OUT2; OUT3; OUT4; C180 PIC18001 100n; PIC18002 COC3; PIR18001; PIR18002; PIR18003; PIR18004; PIR18005; PIR18006; PIR18007; PIR18008; COR5; PIR18101; PIR18102; PIR18103; PIR18105; PIR18104; PIR18106; PIR18107; PIR18108; COR6; PIU18001; PIU18002; PIU18003; PIU18004; PIU18005; PIU18006; PIU18007; PIU18008; PIU18009; PIU180010; PIU180011; PIU180012; PIU180013; PIU180014; COU2; PIC18001; POOUT2; POOUT1; POOUT3; POOUT4; POIN1; POIN3 PIU18005; PIU180010 POIN4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

D | D
C | C
B | B
A | A

C280
100n

V5A

IO0
IO1

COM

MUX

B1 1

GND | 2
B0 3 | A | 4

VCC 5

S 6

U280

NC7SB3157P6X

GNDA | GNDA

PIC28001

# PIC28002 COC125

PIU28001

PIU28002

PIU28003 | PIU28004

PIU28005

PIU28006

## COU104

PIC28001

PIU28002

POIO1 PIU28001

POIO0 PIU28003 | PIU28004 POCOM

PIU28006 POMUX

# PIC28002 PIU28005

POIO00Mux3 | POCOM0Mux3
POIO10Mux3 | POMUX0Mux3

Vdd 4; Vss 6; MCP6004; GNDA; OUT1; OUT2; OUT3; OUT4; C185 PIC18501 100n; PIC18502 COC3; PIR18501; PIR18502; PIR18503; PIR18504; PIR18505; PIR18506; PIR18507; PIR18508; COR5; PIR18601; PIR18602; PIR18603; PIR18605; PIR18604; PIR18606; PIR18607; PIR18608; COR6; PIU18501; PIU18502; PIU18503; PIU18504; PIU18505; PIU18506; PIU18507; PIU18508; PIU18509; PIU185010; PIU185011; PIU185012; PIU185013; PIU185014; COU2; PIC18501; POOUT2; POOUT1; POOUT3; POOUT4; POIN1; POIN3 PIU18505; PIU185010 POIN4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

D | D
C | C
B | B
A | A

C285
100n

V5A

IO0
IO1

COM

MUX

B1 1

GND | 2
B0 3 | A | 4

VCC 5

S 6

U285

NC7SB3157P6X

GNDA | GNDA

PIC28501

# PIC28502 COC125

PIU28501

PIU28502

PIU28503 | PIU28504

PIU28505

PIU28506

## COU104

PIC28501

PIU28502

POIO1 PIU28501

POIO0 PIU28503 | PIU28504 POCOM

PIU28506 POMUX
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

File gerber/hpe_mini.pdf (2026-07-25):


4.7k GND GND
GND test padsLEDs Power

for closed stages, track FOR OFF ROAD PURPOSES ONLY

http://www.hpe-minipr.com/



Id: 3/9 Title: File: LS_weak.kicad_sch Sheet: /LS_WEAK/


Id: 4/9 Title: File: MAP.kicad_sch Sheet: /MAP/


Id: 5/9 Title: File: DOUBLE_PU.kicad_sch Sheet: /DOUBLE_PU/


Id: 6/9 Title: File: TACH_PU.kicad_sch Sheet: /TACH_PU/



Id: 8/9 Title: File: PD2.kicad_sch Sheet: /PD2/ GND


Id: 9/9 Title: File: HS2.kicad_sch Sheet: /HS2/

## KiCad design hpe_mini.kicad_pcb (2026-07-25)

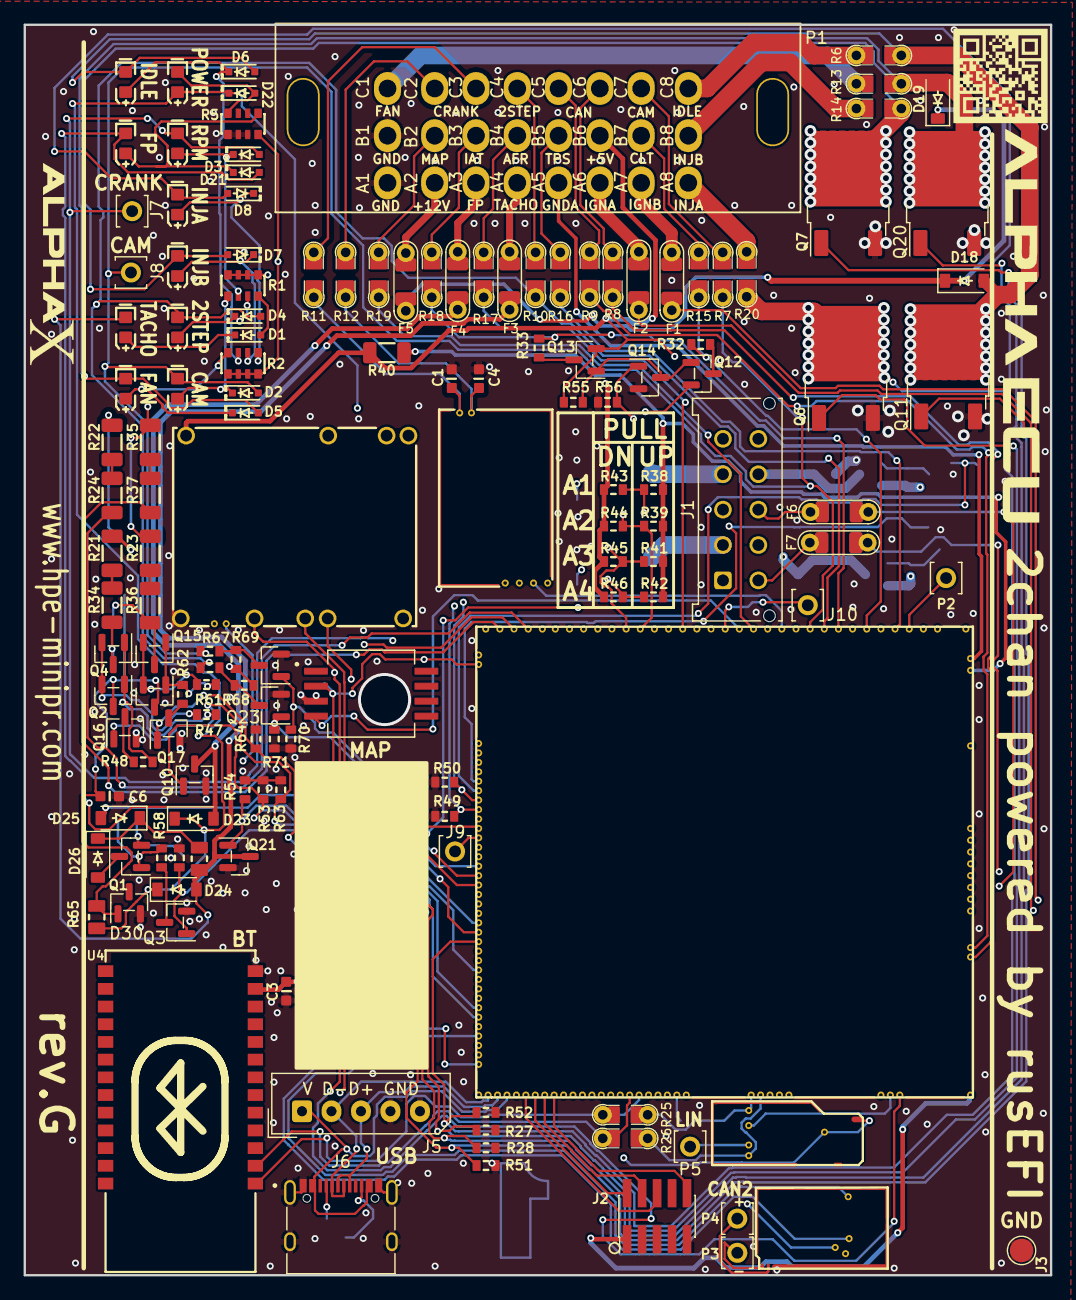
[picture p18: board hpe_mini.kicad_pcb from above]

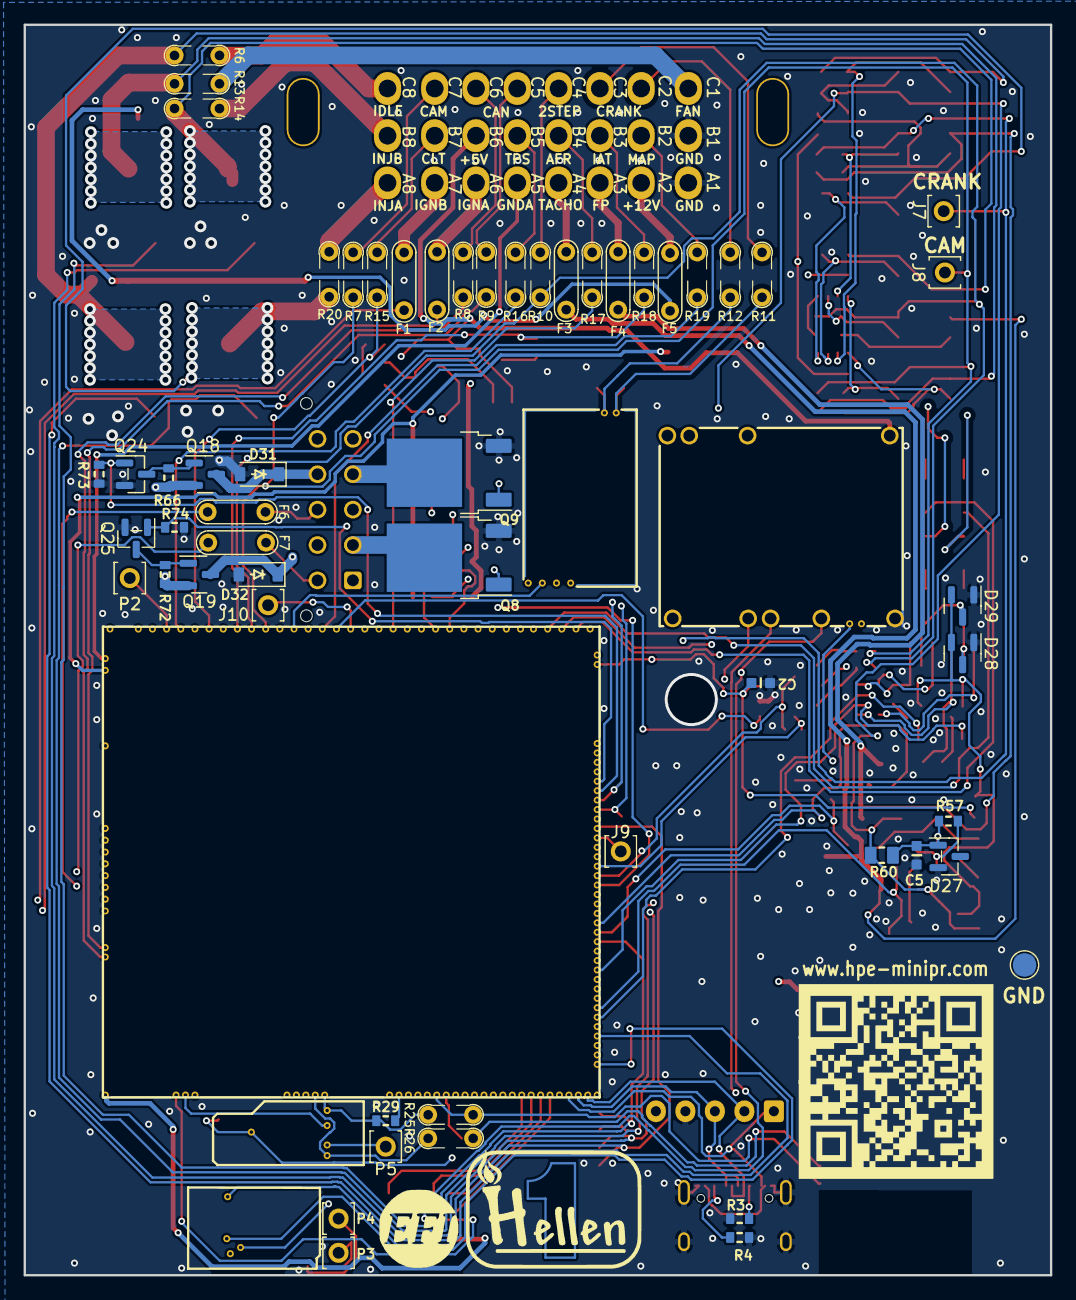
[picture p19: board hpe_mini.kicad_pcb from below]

Board: 4 copper layers, 87.0 x 106.0 mm, 171 parts (27 on the bottom side), 140 nets.

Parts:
C1, C4: C0603
C2, C3, C5, C6: 100n; C0603
D1, D2, D3, D4, D5, D6, D7, D8, D21, D22: 1N4148WS; SOD-323
D9, D13, D14, D15, D16, D17: LED-RED-0603; LED-0603
D10, D11, D12: LED-WHITE-0603; LED-0603
D18, D19, D23, D24, D25, D26, D31, D32: B5819W; SOD-123
D20: LED-GREEN-0603; LED-0603
D27, D30: PSM712-LF; SOT-23
D28, D29: BAT54S; SOT-23
F1, F2, F6, F7: nSMD005; PAD-1206-PAD
F3, F4: nSMD050; PAD-1206-PAD
F5: 12H1500D; PAD-1206-PAD
G2, G3: LOGO
G4: LOGO_AlphaECU; hpe-mini_logo_AlphaECU
G5: LOGO_hpe-mini; hpe-mini_logo_hpe-mini
G6: HPE-MINI_QR_CODE; hpe-mini_qr_code
J1: 430451012; Molex_Micro-Fit_3.0_43045-1012_2x05_P3.00mm_Vertical
J2: Cortex_Debug; PinHeader_2x05_P1.27mm_Vertical_SMD
J3, J4: Conn_01x01; TestPoint_Pad_D2.0mm
J5: Conn_01x05_Male; Molex_SPOX_5267-05A_1x05_P2.50mm_Vertical
J6: USB_C_Receptacle_USB2.0; USB_C_Receptacle_XKB_U262-16XN-4BVC11
J7, J8, J9, J10: Pad; PAD-TH
M1: Module-power_12and5V-0.2; power_12and5V
M2: Module-mega-mcu144-0.5; mega-mcu144
M3: Module-vr-max9924-0.1; vr-max9924
M4: Module-lin-0.1; lin
M8: Module-can-0.1; can
P1: HCCPHPE24BKA90F; 33311-24AW-2
P2, P3, P4, P5: Pad; PAD-TH
Q1, Q2, Q4, Q5, Q12, Q13, Q15: AO3401A; SOT-23
Q3, Q10, Q14, Q16, Q17, Q21, Q22, Q23, Q24, Q25: AO3400A; SOT-23
Q6, Q7, Q8, Q9, Q11, Q20: VND14NV04-E; DPAK
Q18, Q19: PJM2319PSA; SOT-23
R1, R2, R5: 4.7k; R0603-4
R3, R4: 5.6k; R0603
R6, R7, R8, R9, R10, R11, R12, R13, R14, R15, R16, R17, R18, R19, R20, R25, R26: Jumper-Pad-Pad; PAD-0805-PAD
R21, R23, R34, R36: 2k; R1206
R22, R24, R35, R37: 4.7k; R1206
R27, R28, R29, R47, R48, R49, R50, R51, R52, R53, R54, R55, R56, R57, R58, R59, R61, R62, R63, R64, R66, R70, R71, R72, R73, R74: 4.7k; R0603
R30, R67: 3.3k; R0603
R31: 750; R0805
R32, R33: 2.7k; R0603
R38, R39, R41, R42: DNP; R0603
R40: SMD1206B035TF/16; R1206
R43, R44, R45, R46: 680k; R0603
R60: 220; R0805
R65: 470; R0805
R68, R69: 1.2k; R0603
U1: MPXHZ6400AC6T1; MPXH6400A-SSOP8
U4: JDY-33

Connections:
+3V3: J2.1, M2.N22 (V33), M2.N32 (V33), R29.1
+5V: M1.E4 (V5), M2.N31 (VCC), R1.1, R1.2, R1.3, R1.4
+5VA: C2.2, D25.2 (A), M2.E38 (V5A_SWITCHABLE), M2.N30 (V5A_SWITCHABLE), M2.W2 (V5A_SWITCHABLE), M3.E4 (V5_IN), M4.V3 (5V), M8.V1 (V5), R38.2, R39.2, R40.1, R41.2, R42.2, U1.2 (Vs)
+5VAS: M1.V4 (5VP), P1.14 (B6), Q12.3 (S), Q13.3 (S), R40.2, R55.2, R68.2, R69.2
+12V: M1.E2 (V12), M4.N1 (12V), M4.V1 (12V), R2.1, R2.2, R2.3, R2.4, R5.4
+12V_RAW: D18.1 (K), D19.1 (K), D20.1 (A), D22.1 (K), D23.1 (K), D24.1 (K), F5.2, M1.V1 (V12_PERM), M1.V2 (IN_VIGN), M1.V3 (V12_RAW), Q18.2 (S), Q19.2 (S), R60.2, R65.2, R66.2, R72.2
/2STEP_PULLDOWN: M2.E23 (OUT_IO7), Q23.1 (G), R71.1
/A2: F5.1, P1.2 (A2)
/A3: F4.1, P1.3 (A3)
/A4: F3.1, P1.4 (A4)
/A6: F2.1, P1.6 (A6)
/A7: F1.1, P1.7 (A7)
/A8: P1.8 (A8), R20.2
/AIN1: J1.1, M2.S13 (IN_AUX1), R38.1, R43.2
/AIN2: J1.3, M2.S12 (IN_AUX2), R39.1, R44.2
/AIN3: J1.5, M2.S11 (IN_AUX3), R41.1, R45.2
/AIN4: J1.7, M2.S10 (IN_AUX4), R42.1, R46.2
/B2: P1.10 (B2), R19.2
/B3: P1.11 (B3), R18.2
/B4: P1.12 (B4), R17.2
/B5: P1.13 (B5), R16.2
/B7: P1.15 (B7), R15.2
/B8: P1.16 (B8), R14.1
/BT_3V3: C3.2, M2.N28 (V33_SWITCHABLE), M8.V2 (CAN_VIO), U4.12 (3V3)
/C1: P1.17 (C1), R13.2
/C2: P1.18 (C2), R12.2
/C3: P1.19 (C3), R11.2
/C4: P1.20 (C4), R10.2
/C5: P1.21 (C5), R9.2
/C6: P1.22 (C6), R8.2
/C7: P1.23 (C7), R7.2
/C8: P1.24 (C8), R6.2
/CAM_PULLDOWN: M2.E22 (OUT_IO8), Q22.1 (G), R70.1
/CAN2+: M8.S2 (CANH), P4.1
/CAN2-: M8.S1 (CANL), P3.1
/CAN2_RX: M2.E4 (SPI2_CS), M8.V6 (CAN_RX)
/CAN2_TX: M2.E1 (SPI2_SCK), M8.V5 (CAN_TX)
/CAN+: M2.W12 (CANH), R9.1
/CAN-: M2.W13 (CANL), R8.1
/CRANK_N_PULLUP: M2.E7 (OUT_IO5), Q17.1 (G), R64.2
/CRANK_P_PULLUP: M2.E12 (OUT_IO2), Q16.1 (G), R63.2
/FAN_RELAY: M2.E15 (OUT_PWM4), Q20.1 (IN), R52.1
/HALL1: M2.S4 (IN_D1), R24.1
/HALL2: M2.S2 (IN_D3), R37.1
/HALL_PU2/+12V_LIM: C6.2, D28.2 (K), D29.2 (K), D30.1, Q2.2 (D), Q5.2 (D), R65.1
/HS1: M2.E31 (OUT_INJ5), Q24.1 (G), R73.1
/HS2: M2.E32 (OUT_INJ6), Q25.1 (G), R74.1
/IDLE: M2.E27 (OUT_PWM1), Q11.1 (IN), R51.1
/INJ1: M2.E19 (OUT_INJ1), Q6.1 (IN), R27.1
/INJ2: M2.E18 (OUT_INJ2), Q7.1 (IN), R28.1
/INJ3: M2.E29 (OUT_INJ3), Q8.1 (IN), R49.1
/INJ4: M2.E30 (OUT_INJ4), Q9.1 (IN), R50.1
/IN_2STEP: D4.2 (A), D12.2 (K), M2.S25 (IN_VSS), R10.1, R30.1
/IN_AFR: M2.S15 (IN_O2S2), R17.1
/IN_CAM: D2.2 (A), D10.2 (K), J8.1, M2.S24 (IN_CAM), R7.1, R67.1
/IN_CLT: M2.S28 (IN_CLT), R15.1, R32.2
/IN_CRANK: D3.2 (A), D11.2 (K), J7.1, M2.S22 (IN_CRANK), M3.E3 (OUT)
/IN_CRANK+: C1.2, M3.W2 (VR+), R11.1, R21.2, R22.2
/IN_CRANK-: C4.2, M3.W1 (VR-), R12.1, R23.2, R35.2
/IN_IAT: M2.S26 (IN_IAT), R18.1, R33.2
/IN_MAP2: M2.S20 (IN_MAP2), R19.1
/IN_MAP3: M2.S19 (IN_MAP3), U1.4 (Vout)
/IN_TPS: M2.S30 (IN_TPS), R16.1
/LIN: M4.V4 (LIN), P5.1
/NRESET: J2.10, M2.N9 (nReset)
/OUT_FAN_RELAY: D5.2 (A), D13.2 (K), D19.2 (A), Q20.2 (D), R13.1
/OUT_HS1: D31.1 (K), J1.9, Q18.3 (D)
/OUT_HS2: D32.1 (K), J1.10, Q19.3 (D)
/OUT_IDLE: D6.2 (A), D14.2 (K), D18.2 (A), Q11.2 (D), R6.1
/OUT_IGN1: F2.2, M2.W11 (IGN1)
/OUT_IGN2: F1.2, M2.W10 (IGN2)
/OUT_IGN3: F6.2, M2.W9 (IGN3)
/OUT_IGN4: F7.2, M2.W8 (IGN4)
/OUT_INJ1: D8.2 (A), D16.2 (K), Q6.2 (D), R20.1
/OUT_INJ2: D7.2 (A), D15.2 (K), Q7.2 (D), R14.2
/OUT_INJ3: J1.2, Q8.2 (D)
/OUT_INJ4: J1.4, Q9.2 (D)
/OUT_PUMP_RELAY: D17.2 (K), D21.2 (A), D23.2 (A), F4.2, Q10.2 (D)
/OUT_TACH: D9.2 (K), D24.2 (A), F3.2, Q21.2 (D), R31.2
/PUMP_RELAY: M2.E17 (OUT_PWM2), Q10.1 (G), R53.1
/PWR_EN: M1.E5 (EN_5VP), M2.N29 (OUT_PWR_EN)
/SWCLK: J2.4, M2.N8 (SWCLK)
/SWDIO: J2.2, M2.N7 (SWDIO)
/SWO: J2.6, M2.N6 (SWO)
/TACH: M2.E16 (OUT_PWM3), Q21.1 (G), R54.1
/TACH_PULLUP: M2.E8 (OUT_IO1), Q3.1 (G), R59.2
/TEMP_PULLUP: M2.E21 (OUT_IO4), Q14.1 (G), R56.1
/TLS115_PG: M1.E6 (PG_5VP), M2.S3 (IN_D2)
/UART_RX: M2.N18 (UART2_RX), R25.2, U4.1 (TXD)
/UART_TX: M2.N17 (UART2_TX), R26.2, U4.2 (RXD)
/USB+: J5.3, J6.A6 (D+), J6.B6 (D+), M2.N3 (USBP)
/USB-: J5.2, J6.A7 (D-), J6.B7 (D-), M2.N2 (USBM)
/VBUS: J5.1, J6.A4 (VBUS), J6.A9 (VBUS), J6.B4 (VBUS), J6.B9 (VBUS), M2.N4 (VBUS)
/VIGN: M1.E3 (VIGN), M2.N26 (IN_VIGN)
GND: C1.1, C2.1, C3.1, C4.1, C5.1, C6.1, D27.3, D28.1 (A), D29.1 (A), D30.3, D31.2 (A), D32.2 (A), J2.3, J2.5, J2.9, J3.1, J4.1, J5.4, J5.5, J6.A1 (GND), J6.A12 (GND), J6.B1 (GND), J6.B12 (GND), J6.S1 (SHIELD), M1.S1 (GND), M2.G (GND), M3.G (GND), M4.E1 (GND), M4.S1 (GND), M8.E1 (GND), P1.1 (A1), P1.9 (B1), Q3.3 (S), Q6.3 (S), Q7.3 (S), Q8.3 (S), Q9.3 (S), Q10.3 (S), Q11.3 (S), Q14.3 (S), Q16.3 (S), Q17.3 (S), Q20.3 (S), Q21.3 (S), Q22.3 (S), Q23.3 (S), Q24.3 (S), Q25.3 (S), R3.1, R4.1, R5.1, R5.2, R5.3, R27.2, R28.2, R49.2, R50.2, R51.2, R52.2, R53.2, R54.2, R56.2, R59.1, R63.1, R64.1, R70.2, R71.2, R73.2, R74.2, U1.3 (GND), U4.13 (GND)
GNDA: M2.W1 (GNDA), P1.5 (A5), R43.1, R44.1, R45.1, R46.1
unnamed: D1.2 (A), R1.8
unnamed: D1.1 (K), D9.1 (A)
unnamed: D2.1 (K), D10.1 (A), R1.5
unnamed: D3.1 (K), D11.1 (A), R1.6
unnamed: D4.1 (K), D12.1 (A), R1.7
unnamed: D5.1 (K), D13.1 (A), R2.8
unnamed: D6.1 (K), D14.1 (A), R2.7
unnamed: D7.1 (K), D15.1 (A), R2.6
unnamed: D8.1 (K), D16.1 (A), R2.5
unnamed: D17.1 (A), D21.1 (K), R5.5
unnamed: D20.2 (K), D22.2 (A), R5.8
unnamed: D25.1 (K), D26.1 (K), R31.1
unnamed: D26.2 (A), Q1.2 (D)
unnamed: D28.3 (COM), Q4.2 (D), R34.1
unnamed: D29.3 (COM), Q15.2 (D), R36.1
unnamed: F7.1, J1.6
unnamed: F6.1, J1.8
unnamed: J6.A5 (CC1), R3.2
unnamed: J6.B5 (CC2), R4.2
unnamed: J9.1, M2.E26 (OUT_PWM6)
unnamed: J10.1, M2.S18 (IN_RES3)
unnamed: M2.S31 (IN_PPS), P2.1
unnamed: M2.N24 (UART8_RX), M4.V2 (UART_RX), R25.1, R29.2
unnamed: M2.N25 (UART8_TX), M4.V5 (UART_TX), R26.1
unnamed: Q1.1 (G), R57.1, R58.2
unnamed: C5.2, D27.1, Q1.3 (S), R57.2, R60.1
unnamed: Q2.1 (G), Q4.1 (G), R47.1, R48.2
unnamed: Q2.3 (S), Q4.3 (S), R47.2
unnamed: Q3.2 (D), R58.1
unnamed: Q12.2 (D), R32.1
unnamed: Q12.1 (G), Q13.1 (G), Q14.2 (D), R55.1
unnamed: Q13.2 (D), R33.1
unnamed: Q5.1 (G), Q15.1 (G), R61.1, R62.2
unnamed: Q5.3 (S), Q15.3 (S), R61.2
unnamed: Q16.2 (D), R48.1
unnamed: Q17.2 (D), R62.1
unnamed: Q18.1 (G), Q24.2 (D), R66.1
unnamed: Q19.1 (G), Q25.2 (D), R72.1
unnamed: Q22.2 (D), R67.2, R69.1
unnamed: Q23.2 (D), R30.2, R68.1
unnamed: R21.1, R34.2
unnamed: R22.1, R24.2
unnamed: R23.1, R36.2
unnamed: R35.1, R37.2

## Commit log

2026-07-25 Add clean Hellen One starter structure
    [pinout-template.csv]
2026-07-25 add project file for kicad
    [hpe_mini.kicad_pcb, hpe_mini.kicad_sch]
2026-07-25 add example project stuff for initial repo setup
    [DOUBLE_PU.kicad_sch, HALL_PU2.kicad_sch, HS2.kicad_sch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]
2026-07-25 [skip actions] Auto-generated board v2.1
    [hpe_mini-B_Cu.gbl, hpe_mini-B_Mask.gbs, hpe_mini-B_Paste.gbp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]
